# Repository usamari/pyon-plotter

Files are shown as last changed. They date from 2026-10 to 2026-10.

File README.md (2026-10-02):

License: firmware GPL-3.0-or-later, print files CC BY-NC-SA 4.0, docs CC BY 4.0. Details at the end.

This is a kawaii pen plotter that draws within a 60 mm square.
It runs on its own with three buttons. Each button has a short press and a long press.

This machine was developed to turn leftover guide rails at home into a pen plotter, using inexpensive extra parts. A later version with a more deliberate parts selection is also planned.
A larger version, able to draw up to about 170 mm, is in development.

If you find a problem in the files, please use the contact at the end of this README.
Tips are welcome and do not change the license: https://ko-fi.com/usamari

## BOM

- Arduino Uno × 1
- CNC Shield V3 × 1
- Stepper driver A4988 × 2
- NEMA 17 stepper motor (42 × 42 × 23 mm) × 2
- V-groove bearing pulley (M3 × 12 × 4 mm) × 8
- SG90 servo motor × 1
- MGN9H linear rail (100 mm) × 3
- MGN7C linear rail (55 mm) × 1
- Push button × 3

Quantities are small and are omitted.

- M2 × 6 mm screw
- M3 × 6 mm screw
- M3 × 8 mm screw
- M3 × 20 mm screw
- Washer (M3 × 9 × 1 mm)
- Insert nut (M3, 3–4 mm)
- Set screw (M3, 3–4 mm)
- Spring (we recommend having several sizes available to test)
- Prepare wiring components as necessary.

The design assumes PLA filament.
See the images for the belt routing.

## Wiring

The firmware expects an Arduino Uno and a CNC Shield V3.
Motor A uses the X driver socket. Motor B uses the Y driver socket.
Enable is active low: the motors are energized when D8 is LOW.

| Function | Arduino | CNC Shield V3 | Connect to |
| --- | --- | --- | --- |
| Motor A step | D2 | X STEP | A4988 in X socket |
| Motor A dir | D5 | X DIR | A4988 in X socket |
| Motor B step | D3 | Y STEP | A4988 in Y socket |
| Motor B dir | D6 | Y DIR | A4988 in Y socket |
| Enable | D8 | EN | both drivers, active low |
| Servo signal | D11 | Z limit header | SG90 signal wire |
| Blue Abort | A0 | Abort | button to GND |
| Yellow Hold | A1 | Hold | button to GND |
| Red Resume | A2 | Resume | button to GND |

Buttons use the internal pull-ups. Wire each button between its pin and GND.
Do not add an external pull-up.

The SG90 needs 5 V and GND as well as the signal on D11.
If the servo resets the Arduino, power the servo from a separate 5 V supply and join the grounds.

A long press is 800 ms.
Blue: short = 55 mm square, long = 25 mm circle.
Yellow: short = pattern 1, long = pattern 2.
Red: short = pen up, or stop if a drawing is running. Long = pen down.

## License

Copyright (c) 2026 USAMARI 宇佐まり

These parts are licensed separately:

- Firmware: GPL-3.0-or-later. See LICENSE.
  It uses AccelStepper (Mike McCauley, GPL) and the Arduino Servo library (LGPL-2.1).
- Print files and mechanical design (STL, STEP): CC BY-NC-SA 4.0. See LICENSE-hardware.
  Non-commercial use, modification, and sharing are allowed. Sale is not allowed without permission.
- Documentation, including this README and images: CC BY 4.0. See LICENSE-docs.

A license applies only to the files it names. The GPL does not apply to the print files, and CC BY-NC-SA 4.0 does not apply to the firmware.
This is a summary. If it differs from the license files, those files prevail.

## Contact

ukabupukapuka@gmail.com
https://x.com/8_senkou

## Tips

https://ko-fi.com/usamari

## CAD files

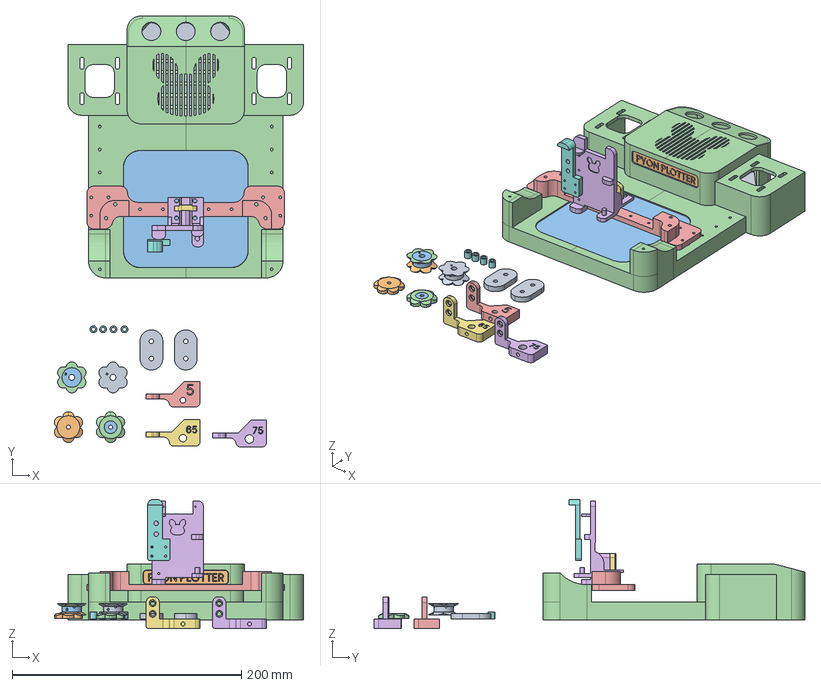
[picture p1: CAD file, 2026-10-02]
hardware-pyon-plotter-60/pyon-plotter-60/pyonplotter60-v1.0.stp
217.7 x 376.2 x 112.7 mm

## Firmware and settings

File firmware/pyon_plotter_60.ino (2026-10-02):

// Pyon plotter 60 firmware
// Copyright (c) 2026 USAMARI
//
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
// Third-party components, not written by the copyright holder above:
//   AccelStepper, Copyright (C) Mike McCauley, GPL
//   https://www.airspayce.com/mikem/arduino/AccelStepper/
//   Arduino Servo library, LGPL-2.1
//   https://github.com/arduino-libraries/Servo

#include <AccelStepper.h>
#include <MultiStepper.h>
#include <Servo.h>
#include <avr/pgmspace.h>
#include <math.h>

// 青 Abort: テスト描画 / blue: test draw
const int BTN_ABORT  = A0;
// 黄 Hold: 本番描画 / yellow: artwork
const int BTN_HOLD   = A1;
// 赤 Resume: ペンと停止 / red: pen and stop
const int BTN_RESUME = A2;

const int PIN_A_STEP = 2;
const int PIN_A_DIR  = 5;
const int PIN_B_STEP = 3;
const int PIN_B_DIR  = 6;
const int PIN_EN     = 8;
const int PIN_SERVO  = 11;

const float STEPS_PER_MM = 50.0;
const float MAX_SPEED    = 500.0;
const float ACCEL        = 5000.0;
const float MAX_X        = 60.0;  // 可動 60mm角 / 60 mm square
const float MAX_Y        = 60.0;
const float PARK_X       = 0.0;
const float PARK_Y       = 60.0;

const int SERVO_UP   = 80;
const int SERVO_DOWN = 130;
const int SERVO_WAIT = 400;
const int LONG_MS    = 800;  // 長押し判定 / long-press threshold

AccelStepper motorA(AccelStepper::DRIVER, PIN_A_STEP, PIN_A_DIR);
AccelStepper motorB(AccelStepper::DRIVER, PIN_B_STEP, PIN_B_DIR);
MultiStepper steppers;
Servo pen;

enum State { IDLE, DRAWING };
State state = IDLE;

bool lastAbort = HIGH, lastHold = HIGH, lastResume = HIGH;
unsigned long stopLowSince = 0;

// ============================================================
// 絵柄1: 黄ボタン短押し / artwork 1: yellow short press
// 下の R"NC( と )NC" の間だけを差し替える。引用符は消さない。
// Replace only the lines between R"NC( and )NC". Keep the quotes.
// ============================================================
const char pattern1_nc[] PROGMEM = R"NC(
)NC";

// ============================================================
// 絵柄2: 黄ボタン長押し / artwork 2: yellow long press
// 下の R"NC( と )NC" の間だけを差し替える。引用符は消さない。
// Replace only the lines between R"NC( and )NC". Keep the quotes.
// ============================================================
const char pattern2_nc[] PROGMEM = R"NC(
)NC";

void motorsEnable(bool on) {
  digitalWrite(PIN_EN, on ? LOW : HIGH);
}

void setPenUp() {
  pen.attach(PIN_SERVO);
  pen.write(SERVO_UP);
  delay(SERVO_WAIT);
}

void setPenDown() {
  pen.attach(PIN_SERVO);
  pen.write(SERVO_DOWN);
  delay(SERVO_WAIT);
}

// 押した瞬間だけ true / true on press edge
bool clicked(int pin, bool &last) {
  bool now = digitalRead(pin);
  bool hit = (last == HIGH && now == LOW);
  last = now;
  return hit;
}

// 離すか2秒まで測る / hold time until release or 2 s
int holdTime(int pin) {
  unsigned long t0 = millis();
  while (digitalRead(pin) == LOW) {
    if (millis() - t0 > 2000) break;
  }
  delay(30);
  return (int)(millis() - t0);
}

// 描画中の赤短押し / red button held while drawing
bool stopHeld() {
  if (digitalRead(BTN_RESUME) != LOW) {
    stopLowSince = 0;
    return false;
  }
  if (stopLowSince == 0) stopLowSince = millis();
  return (millis() - stopLowSince) >= 100;
}

void xyToMotors(float x, float y, long pos[2]) {
  pos[0] = lround((x + y) * STEPS_PER_MM);
  pos[1] = lround((x - y) * STEPS_PER_MM);
}

bool moveToXY(float x, float y) {
  if (x < 0) x = 0;
  if (y < 0) y = 0;
  if (x > MAX_X) x = MAX_X;
  if (y > MAX_Y) y = MAX_Y;
  long pos[2];
  xyToMotors(x, y, pos);
  steppers.moveTo(pos);
  while (steppers.run()) {
    if (stopHeld()) return false;
  }
  return true;
}

void doEstop() {
  setPenUp();
  motorsEnable(false);
  motorA.stop();
  motorB.stop();
  state = IDLE;
}

bool beginDraw() {
  state = DRAWING;
  motorsEnable(true);
  setPenUp();
  motorA.setCurrentPosition(0);
  motorB.setCurrentPosition(0);
  stopLowSince = 0;
  return true;
}

bool endDraw() {
  setPenUp();
  delay(200);
  if (!moveToXY(PARK_X, PARK_Y)) {
    doEstop();
    return false;
  }
  motorsEnable(false);
  state = IDLE;
  return true;
}

// 中央55mm正方形 / 55 mm square, centered
bool drawSquare55() {
  beginDraw();
  const float a = 2.5f;   // (60-55)/2
  const float b = 57.5f;
  if (!moveToXY(a, a)) { doEstop(); return false; }
  setPenDown();
  if (!moveToXY(b, a) || !moveToXY(b, b) ||
      !moveToXY(a, b) || !moveToXY(a, a)) {
    doEstop();
    return false;
  }
  return endDraw();
}

// 直径25mm円、24辺 / 25 mm circle, 24 chords
bool drawCircle25() {
  beginDraw();
  const float cx = 30.0f, cy = 30.0f, r = 12.5f;
  const int n = 24;
  if (!moveToXY(cx + r, cy)) { doEstop(); return false; }
  setPenDown();
  for (int i = 1; i <= n; i++) {
    float a = 2.0f * PI * i / n;
    if (!moveToXY(cx + r * cos(a), cy + r * sin(a))) {
      doEstop();
      return false;
    }
  }
  return endDraw();
}

bool readLine_P(const char *src, int &idx, char *buf, int buflen) {
  int n = 0;
  while (true) {
    char c = pgm_read_byte(src + idx);
    if (c == 0) {
      buf[n] = 0;
      return n > 0;
    }
    idx++;
    if (c == '\r') continue;
    if (c == '\n') break;
    if (n < buflen - 1) buf[n++] = c;
  }
  buf[n] = 0;
  return true;
}

bool parseNumber(const char *s, int &i, float &out) {
  while (s[i] == ' ') i++;
  char *end;
  out = strtod(s + i, &end);
  if (end == s + i) return false;
  i = end - s;
  return true;
}

bool runGCode_P(const char *src) {
  if (!src || !pgm_read_byte(src)) return true;
  beginDraw();
  float x = 0, y = 0;
  int idx = 0;
  char line[96];

  while (readLine_P(src, idx, line, sizeof(line))) {
    if (stopHeld()) { doEstop(); return false; }
    char *p = line;
    while (*p == ' ' || *p == '\t') p++;
    if (*p == 0 || *p == ';' || *p == '(') continue;

    int g = -1, m = -1, s = -1;
    bool hasX = false, hasY = false;
    float nx = x, ny = y, f = -1;
    int i = 0;
    while (p[i]) {
      char c = p[i];
      if (c == ';' || c == '(') break;
      if (c == ' ' || c == '\t') { i++; continue; }
      if (c >= 'a' && c <= 'z') c -= 32;
      i++;
      float v;
      if (!parseNumber(p, i, v)) break;
      if      (c == 'G') g = (int)v;
      else if (c == 'M') m = (int)v;
      else if (c == 'X') { nx = v; hasX = true; }
      else if (c == 'Y') { ny = v; hasY = true; }
      else if (c == 'S') s = (int)v;
      else if (c == 'F') f = v;
    }
    if (m == 5) setPenUp();
    if (m == 3 || m == 4) {
      if (s <= 0) setPenUp();
      else setPenDown();
    }
    if (f >= 1500) setPenUp();
    if (f > 0 && f < 1500) setPenDown();
    if ((g == 0 || g == 1 || hasX || hasY) && (hasX || hasY)) {
      if (hasX) x = nx;
      if (hasY) y = ny;
      if (!moveToXY(x, y)) { doEstop(); return false; }
    }
  }
  return endDraw();
}

void setup() {
  pinMode(PIN_EN, OUTPUT);
  motorsEnable(false);
  pinMode(BTN_ABORT, INPUT_PULLUP);
  pinMode(BTN_HOLD, INPUT_PULLUP);
  pinMode(BTN_RESUME, INPUT_PULLUP);
  lastAbort  = digitalRead(BTN_ABORT);
  lastHold   = digitalRead(BTN_HOLD);
  lastResume = digitalRead(BTN_RESUME);

  motorA.setMaxSpeed(MAX_SPEED);
  motorB.setMaxSpeed(MAX_SPEED);
  motorA.setAcceleration(ACCEL);
  motorB.setAcceleration(ACCEL);
  steppers.addStepper(motorA);
  steppers.addStepper(motorB);

  setPenUp();
  motorA.setCurrentPosition(0);
  motorB.setCurrentPosition(0);
  state = IDLE;
}

void loop() {
  // 赤: 短押し=上げ（描画中は停止）、長押し=下げ
  // red: short = pen up (estop if drawing), long = pen down
  if (clicked(BTN_RESUME, lastResume)) {
    if (holdTime(BTN_RESUME) >= LONG_MS) setPenDown();
    else if (state == DRAWING) doEstop();
    else setPenUp();
    return;
  }
  if (state != IDLE) return;

  // 青: 短押し=正方形、長押し=円 / blue: short square, long circle
  if (clicked(BTN_ABORT, lastAbort)) {
    if (holdTime(BTN_ABORT) >= LONG_MS) drawCircle25();
    else drawSquare55();
    return;
  }
  // 黄: 短押し=絵柄1、長押し=絵柄2 / yellow: short art1, long art2
  if (clicked(BTN_HOLD, lastHold)) {
    runGCode_P(holdTime(BTN_HOLD) >= LONG_MS ? pattern2_nc : pattern1_nc);
  }
}

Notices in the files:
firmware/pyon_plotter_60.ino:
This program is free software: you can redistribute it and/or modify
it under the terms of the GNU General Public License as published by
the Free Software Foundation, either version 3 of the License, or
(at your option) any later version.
